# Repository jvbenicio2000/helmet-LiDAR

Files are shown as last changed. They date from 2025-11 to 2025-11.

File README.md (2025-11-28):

# Helmet-LiDAR

Capacete assistivo com sensor ultrassônico rotativo e feedback tátil vibratório para pessoas com deficiência visual.

## Descrição do Projeto

A ideia é fazer um capacete que consiga, através de um sensor ultrassônico que mede as distâncias e o uso de um motor de passo para movimentar este sensor 360°, acionar quatro motores que vibram e estão posicionados do lado direito, esquerdo, na frente e atrás de um usuário com deficiência visual, a fim de informá-lo se existem obstáculos na frente, atrás ou de qualquer um dos lados.

## Estrutura do Repositório

- **3D-Print:** Contém os arquivos de modelo 3D para a impressão das peças do capacete e suportes dos componentes.
- **Electronics:** Contém os esquemas elétricos, layout da placa de circuito impresso (PCI) e outras informações relacionadas à eletrônica do projeto.
- **Coding:** Contém o código-fonte para o microcontrolador (por exemplo, Arduino ou ESP32) que controla o sensor, os motores e a lógica do sistema.
- **Bill-of-Materials:** Contém a lista de todos os componentes eletrônicos e materiais necessários para a construção do projeto.

## Autores

- João Victor Benício
- Vinicius Macedo Escudeiro
- Bruno Xia
- Raul Perez Silva

### Instituição

Instituto Mauá de Tecnologia

## Matérias Relacionadas

- Instrumentação
- Microcontroladores

## Relatório do Projeto

Para uma documentação completa, incluindo a fundamentação teórica, detalhes de implementação, testes e resultados, consulte o relatório principal do projeto:

**[Relatório Final (PDF)](./relatorio_final.pdf)**

## Funcionalidade Adicional: Rastreamento GPS

Além do sistema de detecção de obstáculos, o projeto inclui uma funcionalidade secundária de **rastreamento por GPS**. Utilizando uma segunda Raspberry Pi Pico, o sistema lê as coordenadas de um módulo GPS NEO-6M e as transmite via Bluetooth para um dispositivo pareado, permitindo o monitoramento remoto da localização do usuário.

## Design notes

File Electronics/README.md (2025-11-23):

# Eletrônica

Esta pasta contém os arquivos relacionados ao hardware eletrônico do projeto, incluindo o esquema elétrico e, futuramente, o layout da Placa de Circuito Impresso (PCB).

## Esquema Elétrico (`schematic.jpeg`)

O arquivo `schematic.jpeg` apresenta o diagrama de conexões entre o microcontrolador Raspberry Pi Pico e os principais periféricos do sistema.

### Visão Geral dos Componentes

- **Microcontrolador (RP):** O cérebro do projeto é um Raspberry Pi Pico.
- **Driver do Motor de Passo (TMC2209):** Controla o `MOTOR DE PASSO` com alta precisão, responsável por girar o sensor ultrassônico.
- **Regulador de Tensão (VI):** Converte a `FONTE 9V` (conector J1) para uma tensão adequada para alimentar os componentes.
- **Conectores:**
  - `PH1` e `PH2`: Conexão para o sensor ultrassônico (Trigger e Echo).
  - `DIGITAIS PONTE H`: Conector de 8 pinos para os drivers L298N que acionam os motores de vibração.
  - `PWM'S`: Conector de 4 pinos para os sinais PWM que controlam a intensidade dos motores de vibração.
  - `J4`: Conector de 4 pinos, provavelmente para o módulo GPS ou outro periférico.

### Mapeamento de Pinos (Conforme o Esquema)

A tabela abaixo detalha as conexões entre o Raspberry Pi Pico e os demais componentes, conforme ilustrado no esquema elétrico.

| Pino (GPIO) do Pico | Componente Conectado | Função |
|---|---|---|
| GP0 - GP7 | Conector `DIGITAIS PONTE H` | Sinais de controle para os drivers L298N. |
| GP8 - GP11 | Conector `PWM'S` | Sinais PWM para os 4 motores de vibração. |
| GP12 | TMC2209 | Sinal de `STEP` para o motor de passo. |
| GP13 | TMC2209 | Sinal de `DIR` (Direção) para o motor de passo. |
| GP14 | Conector `PH1` | Sinal de `TRIGGER` para o sensor ultrassônico. |
| GP15 | Conector `PH2` | Sinal de `ECHO` do sensor ultrassônico. |
| GP21 | TMC2209 | Sinal de `EN` (Enable) para o driver do motor. |

**Observação Importante:** O mapeamento de pinos neste esquema elétrico **difere** do que está definido no arquivo `Coding/main.c`. Será necessário ajustar o código-fonte para refletir as conexões do hardware final ou vice-versa. O esquema representa a documentação de hardware mais recente.

## Projeto Proteus (`Proteus/`)

A subpasta `Proteus/` contém os arquivos de design do circuito e da PCB (Placa de Circuito Impresso) desenvolvidos no software Proteus.

- **`PCBProjeto.pdsprj`**: Este é o arquivo principal do projeto Proteus, que inclui tanto o diagrama esquemático quanto o layout da PCB.
- **`*.workspace`**: Arquivo de configuração do ambiente de trabalho (workspace) do Proteus, que salva as configurações da sua sessão de trabalho, como janelas abertas e zoom.

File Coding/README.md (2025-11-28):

# Código-Fonte

Esta pasta contém o código-fonte para o microcontrolador do projeto Helmet-LiDAR.

## `main.c`

- **Microcontrolador Alvo:** Raspberry Pi Pico
- **Linguagem:** C

### Descrição

Este é o programa principal que orquestra todo o funcionamento do capacete. A lógica implementada realiza as seguintes tarefas:

1.  **Controle do Motor de Passo:** Utiliza um driver TMC2209 para girar o motor de passo em um ciclo contínuo: 360° no sentido horário, seguido por 360° no sentido anti-horário.

2.  **Varredura do Ambiente:** Realiza 12 medições de distância com o sensor ultrassônico a cada volta completa (uma medição a cada 30°).

3.  **Leitura do Sensor Ultrassônico:** Envia um pulso de trigger e mede a duração do pulso de echo para calcular a distância de obstáculos em centímetros.

4.  **Controle dos Motores de Vibração:**
    - A intensidade da vibração é inversamente proporcional à distância medida (quanto mais perto o obstáculo, mais forte a vibração).
    - A direção do obstáculo, determinada pelo ângulo do motor de passo, define qual dos quatro motores de vibração será acionado:
        - **Motor A (Frente):** 0° a 90°
        - **Motor B (Direita):** 90° a 180°
        - **Motor C (Atrás):** 180° a 270°
        - **Motor D (Esquerda):** 270° a 360°
    - O controle da intensidade é feito via PWM (Pulse Width Modulation).

### Pinos Utilizados (Raspberry Pi Pico)

| Função | Pino (GPIO) |
|---|---|
| **Sensor Ultrassônico** | |
| TRIGGER | 2 |
| ECHO | 3 |
| **Motores de Vibração** | |
| Motor A (Frente) | 6 |
| Motor B (Direita) | 8 |
| Motor C (Atrás) | 10 |
| Motor D (Esquerda) | 12 |
| **Motor de Passo (TMC2209)** | |
| STEP | 13 |
| DIR | 21 |
| EN | 5 |

### Compilação

Para compilar este projeto, é necessário ter o ambiente de desenvolvimento para o Raspberry Pi Pico configurado. Siga o guia oficial "Getting started with Raspberry Pi Pico" para mais detalhes.

## `gps_bluetooth.py`

- **Microcontrolador Alvo:** Raspberry Pi Pico W
- **Linguagem:** MicroPython

### Descrição

Este script é responsável por uma funcionalidade secundária do projeto: **rastreamento por GPS e comunicação via Bluetooth**.

1.  **Leitura do GPS:** O código utiliza uma comunicação serial (UART) para ler os dados brutos (sentenças NMEA) de um módulo GPS NEO-6M.

2.  **Parsing de Dados:** Ele processa especificamente as sentenças `$GPRMC` ou `$GNRMC`, que contêm as informações essenciais de geolocalização (latitude e longitude).

3.  **Conversão de Coordenadas:** Converte o formato de coordenadas NMEA para o formato de graus decimais, que é mais comum e fácil de usar em mapas.

4.  **Transmissão Bluetooth:** As coordenadas de latitude e longitude formatadas são então enviadas via Bluetooth (usando um módulo HC-05) para um dispositivo pareado, como um smartphone. Isso permite o monitoramento remoto da localização do usuário.

### Pinos Utilizados (Raspberry Pi Pico)

| Função | Pino (GPIO) do Pico | Módulo |
|---|---|---|
| **GPS (UART 1)** | |
| TX | 4 | RX do NEO-6M |
| RX | 5 | TX do NEO-6M |
| **Bluetooth (UART 0)** | |
| TX | 0 | RX do HC-05 |
| RX | 1 | TX do HC-05 |

**Nota:** Este script opera de forma independente do `main.c` e requer uma segunda Raspberry Pi Pico, conforme especificado na lista de materiais.

## `gps_bluetooth.c` (Versão em C)

- **Microcontrolador Alvo:** Raspberry Pi Pico
- **Linguagem:** C (com Raspberry Pi Pico SDK)

### Descrição

Esta é a **versão em C** da funcionalidade de rastreamento GPS, convertida a partir do script MicroPython. As funcionalidades são idênticas:

1.  **Leitura do GPS:** Utiliza a UART1 para ler dados NMEA do módulo GPS NEO-6M.
2.  **Parsing de Dados:** Processa as sentenças `$GPRMC` ou `$GNRMC` para extrair status, latitude e longitude.
3.  **Conversão de Coordenadas:** Converte as coordenadas NMEA para o formato de graus decimais.
4.  **Transmissão Bluetooth:** Envia as coordenadas formatadas via UART0 para um módulo Bluetooth HC-05.

### Pinos Utilizados (Raspberry Pi Pico)

O mapeamento de pinos é o mesmo da versão em Python:

| Função | Pino (GPIO) do Pico | Módulo |
|---|---|---|
| **GPS (UART 1)** | |
| TX | 4 | RX do NEO-6M |
| RX | 5 | TX do NEO-6M |
| **Bluetooth (UART 0)** | |
| TX | 0 | RX do HC-05 |
| RX | 1 | TX do HC-05 |

### Compilação

Para compilar este código, é necessário ter o ambiente de desenvolvimento para o Raspberry Pi Pico SDK configurado. O código deve ser compilado junto com os arquivos de build do SDK (CMakeLists.txt, etc.).

## `main_enhanced.c` (Versão Aprimorada)

- **Microcontrolador Alvo:** Raspberry Pi Pico
- **Linguagem:** C

### Descrição

Esta é uma **versão aprimorada** do código `main.c`, com foco em melhorar a precisão e a estabilidade das medições do sensor ultrassônico.

### Melhorias Implementadas

1.  **Filtro de Média Móvel (`read_distance_filtered()`):**
    -   **Problema Resolvido:** Sensores ultrassônicos podem sofrer com leituras espúrias (picos de ruído) que geram dados incorretos e instáveis.
    -   **Solução:** Em vez de usar uma única leitura, esta função coleta **5 amostras** de distância em rápida sucessão.
    -   Ela então **descarta a menor e a maior** leitura (que são as mais prováveis de serem ruído) e calcula a **média das 3 leituras restantes**.
    -   **Resultado:** A distância retornada é muito mais estável e confiável, reduzindo falsos positivos e tornando a resposta do sistema de vibração mais consistente.

2.  **Código Mais Robusto:** A lógica de ordenação (bubble sort) garante que os valores mínimo e máximo sejam sempre descartados corretamente.

O restante da lógica (controle do motor de passo, PWM, etc.) permanece o mesmo, mas agora opera com dados de distância de maior qualidade.

## `gps_geofencing.py` (Versão Aprimorada com Geofencing)

- **Microcontrolador Alvo:** Raspberry Pi Pico W
- **Linguagem:** MicroPython

### Descrição

Esta é uma **versão avançada** do script de GPS, que adiciona a funcionalidade de **geofencing** (cercas virtuais) para reconhecer pontos de interesse pré-definidos.

### Melhorias e Funcionalidades

1.  **Filtro de Média Móvel (`get_filtered_position()`):**
    -   Assim como no `main_enhanced.c`, este código coleta múltiplas amostras de GPS para calcular uma posição média, resultando em uma localização muito mais estável e precisa.

2.  **Cálculo de Distância Haversine (`distance_m()`):**
    -   Implementa a fórmula de Haversine para calcular com precisão a distância em metros entre duas coordenadas geográficas, levando em conta a curvatura da Terra.

3.  **Geofencing com Waypoints (`check_location()`):**
    -   Você pode definir uma lista de **pontos de interesse** (waypoints) com nome, latitude, longitude e um raio em metros.
    -   O código verifica continuamente se a posição atual do usuário está dentro do raio de algum desses waypoints.

4.  **Notificações de Chegada (`main()`):**
    -   Quando o usuário entra na área de um waypoint, o sistema envia uma notificação via Bluetooth (ex: "Você chegou perto de: Casa").
    -   Ele evita notificações repetidas, enviando o aviso apenas uma vez ao entrar na área.

### Uso

-   **Personalize os Waypoints:** Edite a lista `WAYPOINTS` no código para adicionar os locais de interesse para o usuário.
-   **Ação Personalizada:** No laço principal, há um local marcado (`>>> AQUI você pode colocar a reação do sistema <<<`) onde você pode adicionar uma ação específica quando um waypoint é alcançado (ex: acender um LED, tocar um som, etc.).

## `CMakeLists.txt` (Arquivo de Build)

- **Ambiente:** Raspberry Pi Pico SDK (C/C++)

### Descrição

Este arquivo é um **script de build** para o sistema CMake, que automatiza o processo de compilação de todos os códigos-fonte em C (`.c`) do projeto para o Raspberry Pi Pico.

### Funcionalidades

1.  **Múltiplos Executáveis:** Ele está configurado para compilar **três executáveis independentes** a partir dos seus respectivos arquivos-fonte:
    -   `main` (a partir de `main.c`)
    -   `main_enhanced` (a partir de `main_enhanced.c`)
    -   `gps_bluetooth` (a partir de `gps_bluetooth.c`)

2.  **Gerenciamento de Bibliotecas:** Para cada executável, ele automaticamente vincula (linka) as bibliotecas necessárias do Pico SDK, como `pico_stdlib`, `hardware_pwm`, `hardware_uart`, etc.

3.  **Saída de Depuração:** Habilita a saída de `printf` via USB para todos os executáveis, facilitando a depuração.

4.  **Geração de Arquivos:** Automatiza a criação de todos os formatos de arquivo necessários para gravar no Pico, incluindo:
    -   `.uf2` (para arrastar e soltar na unidade do Pico)
    -   `.bin`
    -   `.hex`

### Como Usar

1.  **Configure o Ambiente:** Certifique-se de ter o [Raspberry Pi Pico SDK](https://github.com/raspberrypi/pico-sdk) e as ferramentas de compilação (CMake, GCC ARM) instalados.

2.  **Crie a Pasta de Build:** Dentro da pasta `Coding/`, crie uma subpasta chamada `build`:
    ```bash
    cd Coding
    mkdir build
    cd build
    ```

3.  **Execute o CMake e o Make:**
    ```bash
    cmake ..
    make
    ```

4.  **Grave no Pico:** Após a compilação, a pasta `build/` conterá os arquivos `.uf2` para cada um dos três executáveis. Basta arrastar o arquivo `.uf2` desejado para a unidade do Pico (que aparece ao conectar o Pico com o botão BOOTSEL pressionado).

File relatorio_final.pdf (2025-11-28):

## DISPOSITIVO VESTÍVEL DE AUXÍLIO À NAVEGAÇÃO PARA DEFICIENTES VISUAIS COM FEEDBACK TÁTIL, SENSORIAMENTO DE OBSTÁCULOS E RASTREAMENTO GPS

João Victor Benício ¹; Raul Perez ¹; Vinícius Escudeiro ¹; Bruno Xia ¹; Andressa Corrente Martins ²; Rodrigo França ²

¹ Aluno do Instituto Mauá de Tecnologia (IMT);

²Professor do Instituto Mauá de Tecnologia(IMT).

Resumo. Este relatório descreve o desenvolvimento de um dispositivo vestível projetado para auxiliar a navegação de deficientes visuais. O sistema integra uma cinta com feedback tátil, um protótipo de radar para detecção de obstáculos e um módulo GPS para rastreamento de localização. O projeto serve como uma investigação preliminar para um futuro Trabalho de Conclusão de Curso (TCC). O sistema é composto por dois circuitos independentes, garantindo a privacidade do usuário ao permitir a desativação do rastreamento por GPS. O primeiro circuito, baseado em um microcontrolador Raspberry Pi Pico W, gerencia um sensor de distância ultrassônico montado em um motor de passo para emular um radar, e aciona quatro motores vibratórios para fornecer feedback tátil direcional. O segundo circuito, também utilizando um Raspberry Pi Pico W, é dedicado ao módulo GPS e à comunicação Bluetooth com uma interface de monitoramento em um aplicativo móvel. O desenvolvimento abrangeu desde a concepção e teste de componentes até a montagem de um protótipo funcional e o desenvolvimento de uma placa de circuito impresso (PCB). Os resultados validam a viabilidade do conceito de feedback tátil para orientação espacial, ao mesmo tempo que expõem as limitações dos componentes de baixo custo, como o alcance do sensor ultrassônico e a precisão do motor de passo.

Introdução

O desenvolvimento de tecnologias assistivas tem como objetivo primordial a promoção da autonomia e da qualidade de vida para pessoas com deficiência. Para indivíduos com deficiência visual, a navegação em ambientes desconhecidos representa um desafio constante, muitas vezes dependendo de auxílios tradicionais como bengalas ou cães-guia. Com o avanço da microeletrônica e dos sistemas embarcados, surgem novas possibilidades para a criação de dispositivos mais sofisticados e eficazes.

Este projeto se insere nesse contexto como um estudo introdutório e exploratório para um futuro Trabalho de Conclusão de Curso (TCC), que ambiciona desenvolver um sistema completo para monitorar e instrumentar um jet-ski, permitindo que deficientes visuais possam pilotá-lo de forma segura através de auxílio tátil ou sonoro. O foco do presente trabalho é a concepção e validação de três subsistemas chave: uma interface de feedback tátil utilizando motores vibratórios, um protótipo de radar para detecção de obstáculos e um sistema de rastreamento de localização via GPS com interface móvel. A integração e o teste desses componentes visam avaliar a viabilidade da abordagem e identificar os desafios técnicos para o projeto final.

O objetivo geral deste trabalho é desenvolver e avaliar um protótipo de dispositivo vestível para auxílio à navegação de deficientes visuais, validando os conceitos de feedback tátil para orientação espacial, sensoriamento de obstáculos com um radar de baixo custo e monitoramento de localização por GPS. Os objetivos específicos incluem testar a interface com motores vibratórios, construindo uma cinta com quatro motores vibratórios e desenvolvendo um sistema que traduza a localização de obstáculos em feedback tátil, variando a intensidade da vibração de acordo com a proximidade. Além disso, busca-se desenvolver um protótipo de radar, montando e programando um sistema de varredura de ambiente utilizando um sensor de distância ultrassônico acoplado a um motor de passo, emulando o funcionamento de um radar para mapear obstáculos em 360°. Por fim, pretende-se analisar o módulo GPS e a comunicação Bluetooth, implementando um circuito independente com um módulo GPS para capturar coordenadas geográficas e transmiti-las via Bluetooth para um aplicativo móvel, compreendendo as dificuldades e limitações da tecnologia, especialmente em relação à privacidade e à estabilidade do sinal.

Material e Métodos

O projeto foi desenvolvido de forma incremental, em seis etapas principais. Na fase de idealização, definiu-se o escopo do projeto, os objetivos e a arquitetura geral do sistema, separando-o em dois subsistemas: radar com feedback tátil e GPS/comunicação. Em seguida, realizou-se a seleção e compra de componentes, escolhendo e adquirindo os dispositivos eletrônicos de acordo com critérios de funcionalidade, custo e disponibilidade.

Depois disso, foi feita a etapa de teste individual de componentes, na qual sensores, atuadores e microcontroladores foram avaliados separadamente para verificar o correto funcionamento e compreender o comportamento de cada um. Concluídos esses testes, passou-se à montagem em protoboard, integrando os componentes em um mesmo circuito, o que permitiu ajustar tanto o hardware quanto a lógica de programação de forma rápida e flexível.

Na sequência, ocorreu o desenvolvimento e a depuração do código. O firmware foi implementado em MicroPython e em linguagem C, conforme a necessidade de cada subsistema, com foco na interação entre sensores e atuadores e em requisitos de desempenho em tempo real. O código passou por ciclos sucessivos de teste e correção para melhorar a estabilidade e a resposta do sistema.

Por fim, foi projetado o esquemático do subsistema de radar, confeccionada a placa de circuito impresso (PCI) e soldados os componentes, resultando em uma montagem mais robusta e confiável em comparação à fase de prototipagem em protoboard.

Tabela 1 – Componentes utilizados no projeto

Componente | Quantidade Especificação | Função no Projeto
Microcontrolador | 2 | Raspberry Pi Pico W | Processamento central dos dois subsistemas
Sensor de Distância | 1 | HC-SR04 | Medição de distância para o radar
Motor de Passo | 1 | NEMA 17 (ou similar) | Rotação do sensor ultrassônico
Driver de Motor de Passo | 1 | TMC2209 | Controle preciso do motor de passo
Motores de Vibração | 4 | Com massa desbalanceada | Atuadores para feedback tátil
Driver Ponte H | 2 | L298N | Controle dos motores de vibração
Módulo GPS | 1 | Módulo GPS genérico | Aquisição de coordenadas geográficas
Módulo Bluetooth | 1 | Integrado ao Pico W | Comunicação com o aplicativo móvel
Placa de Circuito Impresso | 1 | Produzida pela Mauá | Integração dos componentes do subsistema de radar

Fonte de
Alimentação
- Baterias/Fonte
| | externa | Alimentação dos circuitos

Com o objetivo de garantir a privacidade do usuário, a arquitetura do sistema foi dividida em dois circuitos completamente independentes e sem comunicação de dados entre si. O primeiro subsistema é o núcleo da orientação espacial, controlado por um Raspberry Pi Pico W e composto por um radar sintético, uma lógica de atuação e o feedback tátil. O radar sintético consiste em um sensor ultrassônico HC-SR04 montado sobre um motor de passo que realiza uma varredura de 360°, parando em intervalos para que o sensor meça a distância até o obstáculo mais próximo em uma determinada direção. O sistema registra o número de passos do motor para derivar o ângulo de detecção. A lógica de atuação divide o espaço ao redor do usuário em quatro quadrantes (0-90°, 90-180°, 180-270°, 270-360°), e ao detectar um obstáculo, o sistema identifica em qual quadrante ele se encontra e aciona o motor de vibração correspondente. O feedback tátil é composto por quatro motores de vibração posicionados em uma cinta, correspondendo à frente (12h), lateral direita (3h), costas (6h) e lateral esquerda (9h). A intensidade da vibração de cada motor é inversamente proporcional à distância medida, fornecendo uma percepção intuitiva da proximidade do obstáculo.

O segundo subsistema opera de forma autônoma e é responsável pelo rastreamento de localização. Um segundo Raspberry Pi Pico W é conectado a um módulo GPS, lendo continuamente os dados de geolocalização (latitude, longitude, altitude, número de satélites). Os dados de GPS são transmitidos via Bluetooth para um smartphone, onde um aplicativo simples, desenvolvido na plataforma App Inventor, recebe e exibe os dados de localização, permitindo que um acompanhante possa monitorar a posição do usuário em tempo real.

Resultados e Discussão

O desenvolvimento do projeto permitiu alcançar resultados funcionais, validando a prova de conceito, mas também revelou desafios importantes. O sistema, especialmente durante a fase de testes em protoboard, operou conforme o esperado. O radar sintético foi capaz de realizar a varredura do ambiente, e o feedback tátil na cinta respondeu corretamente à detecção de obstáculos, com a intensidade da vibração variando de acordo com a distância. O subsistema de GPS também se mostrou funcional, capturando coordenadas e transmitindo-as com sucesso para o aplicativo de monitoramento, como demonstrado na Figura 1.

Figura 1 – Interface do aplicativo móvel exibindo dados de GPS em tempo real.

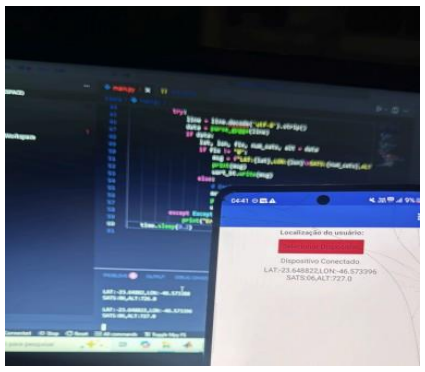
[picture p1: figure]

O desenvolvimento da placa de circuito impresso (Figura 2) para o subsistema de radar representou um avanço significativo em relação à montagem em protoboard, resultando em um protótipo mais estável e compacto. A PCB foi projetada utilizando software de design de circuitos e fabricada nas instalações do Instituto Mauá de Tecnologia. A soldagem dos componentes foi realizada manualmente, garantindo conexões confiáveis e reduzindo problemas de mau contato que eram frequentes na montagem em protoboard.

Figura 2 – Diagrama elétrico desenvolvida para o subsistema de radar.

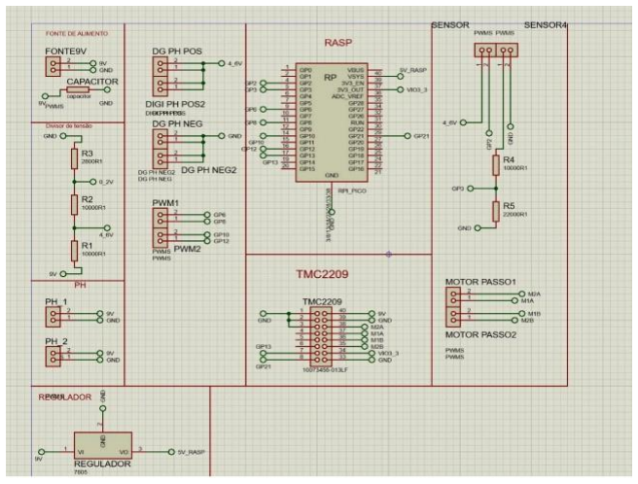
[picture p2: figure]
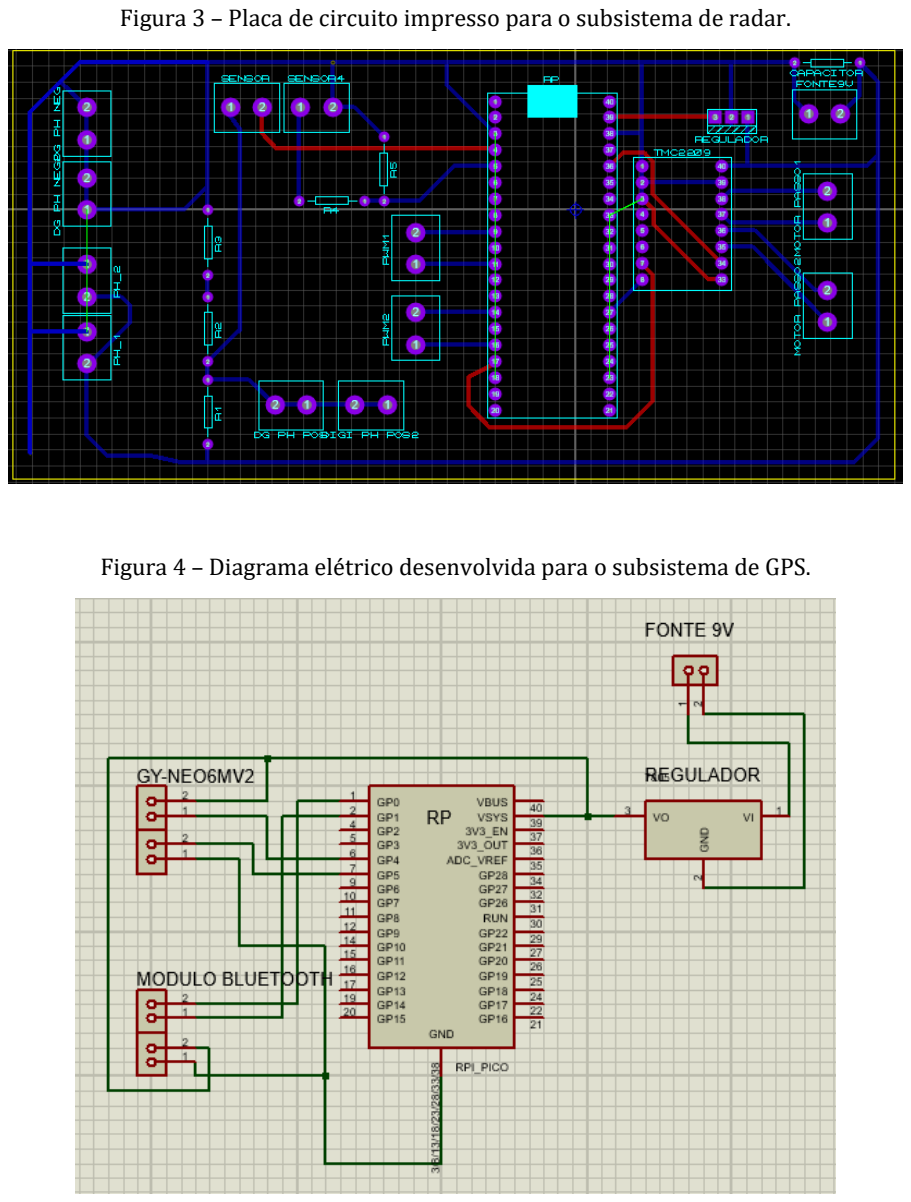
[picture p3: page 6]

Figura 3 – Placa de circuito impresso para o subsistema de radar.

Figura 4 – Diagrama elétrico desenvolvida para o subsistema de GPS.

Figura 5 – Placa de circuito impresso para o subsistema de GPS.

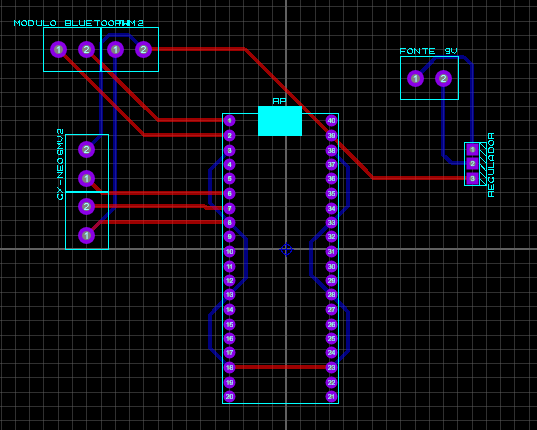
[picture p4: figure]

Rotinas de processamento de posição

O firmware de localização foi estruturado em um conjunto de rotinas responsáveis pelo tratamento das informações de GPS. Inicialmente, as sentenças NMEA recebidas do módulo são filtradas, sendo consideradas apenas aquelas do tipo RMC, por conterem latitude, longitude e o estado de validade da posição. Em seguida, as coordenadas no formato NMEA (ddmm.mmmm) são convertidas para graus decimais, o que facilita a aplicação de operações matemáticas e geodésicas.

Com o objetivo de reduzir o ruído inerente às medições de GPS, o sistema não utiliza uma leitura isolada. Em vez disso, são obtidas sucessivas posições válidas dentro de uma janela de tempo e, a partir delas, calcula-se a média das latitudes e das longitudes. Esse procedimento de filtragem por média aritmética resulta em uma posição geográfica mais estável e representativa do local real em que o dispositivo se encontra.

Uma vez determinada a posição filtrada, o firmware a compara com um conjunto de pontos de interesse pré-cadastrados (waypoints). Cada waypoint é definido por um nome, por uma coordenada em graus decimais e por um raio de detecção em metros. Para cada ponto cadastrado, é calculada a distância entre a posição atual e a posição de referência utilizando a fórmula de Haversine, que fornece uma boa aproximação da distância entre dois pontos na superfície terrestre. Quando a distância calculada é menor ou igual ao raio estabelecido para determinado waypoint, considera-se que o dispositivo se encontra dentro da área desse ponto, e o nome correspondente é retornado para uso nas demais partes do sistema.

Programa principal (função main)

A função main integra as rotinas descritas anteriormente e coordena o funcionamento contínuo do módulo de localização. Após a inicialização dos recursos necessários, o programa entra em um laço cíclico no qual, a cada iteração, solicita uma nova posição geográfica ao bloco de processamento. Caso não seja possível obter uma posição confiável naquele instante, o sistema apenas registra essa condição e informa a ausência de fix, sem alterar o estado dos demais subsistemas.

Quando uma posição válida é obtida, a função main utiliza o resultado filtrado de latitude e longitude para duas finalidades principais: (i) disponibilizar essas informações para fins de monitoramento e registro, e (ii) acionar a rotina de verificação de waypoints. Se essa verificação indicar que a posição atual se encontra dentro da área de algum ponto cadastrado, o programa identifica o nome do local correspondente e gera uma mensagem de chegada, que pode ser encaminhada a um dispositivo externo e/ou utilizada para disparar uma resposta física no protótipo, como a ativação de um indicador luminoso ou de outro atuador.

Dessa forma, o laço principal passa a funcionar como um monitor de localização em tempo real, responsável por transformar coordenadas brutas de GPS em eventos significativos para o projeto, tais como “entrada na área da loja” ou “aproximação de um ponto de interesse pré-definido”.

Desafios e dificuldades

Diversas dificuldades foram encontradas durante o desenvolvimento. O sensor ultrassônico HC-SR04, apesar de seu baixo custo, possui um alcance limitado e um cone de detecção relativamente amplo, o que pode levar a imprecisões. A velocidade de varredura é restrita pela necessidade de rotação do motor de passo e pelo tempo de resposta do sensor. Foi observado que, após uso contínuo, o motor de passo pode perder passos, resultando em um erro acumulado na determinação do ângulo e, consequentemente, na localização do feedback tátil. O módulo GPS apresentou dificuldade em obter sinal em ambientes fechados, uma limitação inerente à tecnologia. A comunicação via Bluetooth também se mostrou suscetível a interferências e perda de conexão com o aumento da distância entre o dispositivo e o smartphone. Problemas de mau contato nos conectores e fios foram uma fonte recorrente de falhas durante a fase de prototipagem. A integração do software com o hardware, especialmente a calibração da resposta do sensor de distância, exigiu depuração extensiva.

Conclusões

O projeto atingiu com sucesso seus objetivos principais, demonstrando a viabilidade de um sistema vestível com feedback tátil para auxílio à navegação. A prova de conceito validou que a utilização de motores vibratórios com intensidade variável é uma forma intuitiva e eficaz de comunicar informações espaciais sobre obstáculos ao usuário. As limitações encontradas, no entanto, são cruciais para a evolução do projeto. A montagem do radar sintético, embora funcional para validação, não se mostra robusta o suficiente para uma aplicação real devido às imprecisões do sensor ultrassônico e à perda de passos do motor. A resolução espacial do feedback, limitada a quatro quadrantes, também pode ser aprimorada para fornecer uma orientação mais precisa. Conclui-se que, embora a abordagem seja promissora, a transição para um produto final, como o sistema de auxílio para pilotagem de jet-ski, exigirá a substituição de componentes chave por soluções de nível comercial e maior robustez.

Com base nas conclusões deste trabalho, as seguintes melhorias são propostas para o desenvolvimento futuro do projeto, visando a aplicação no TCC. Primeiramente, propõe-se aumentar a resolução tátil, utilizando um número maior de motores vibratórios na cinta para fornecer uma indicação de direção mais granular e precisa. Em segundo lugar, sugere-se implementar feedback sonoro, adicionando um fone de ouvido ao sistema para fornecer informações complementares por áudio, como alertas de voz (“Obstáculo à direita”, “Velocidade: 10 km/h”), utilizando o conceito de áudio espacial para indicar a direção. Por fim, recomenda-se substituir o radar sintético, incorporando um módulo de radar comercial (tecnologia de micro-ondas ou LiDAR) para obter uma detecção de obstáculos mais rápida, precisa e com maior alcance, eliminando os problemas mecânicos do motor de passo.

Referências Bibliográficas

Bailey, D.D.; Ollis, D.F. (1986) Biochemical Engineering Fundamentals. 2ⁿᵈ edition. New York, McGraw-Hill.

Vela, F.J.; Gianotti, E.P.; Foresti, E.; Zaiat, M. (1999) Estimation of Substrate Effective Diffusivities in Anaerobic Bioparticles. Environmental Technology, 20, 1163-1170.

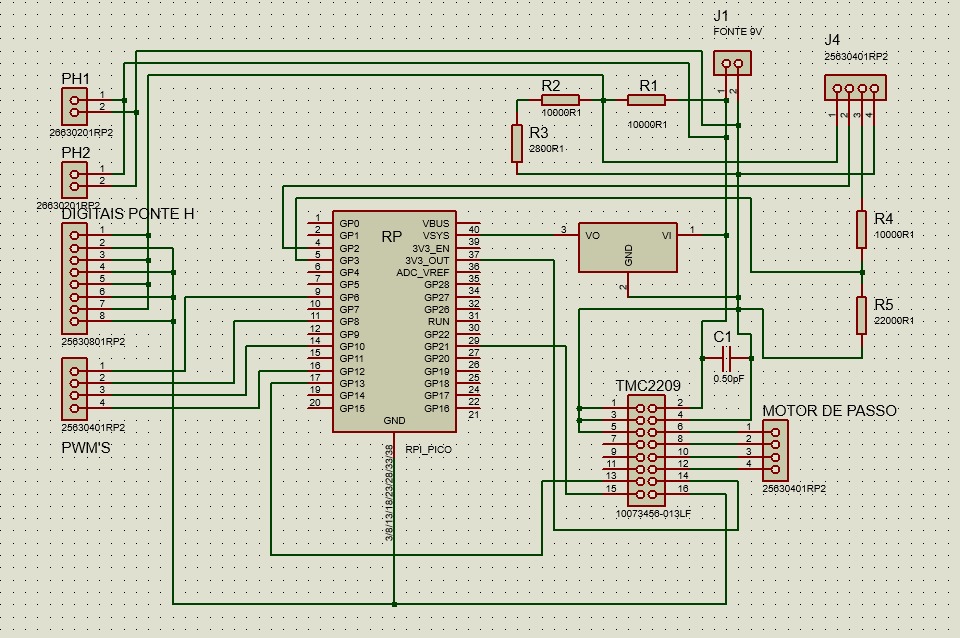
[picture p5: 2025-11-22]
Electronics/schematic.jpeg

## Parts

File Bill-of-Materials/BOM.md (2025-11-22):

# Lista de Materiais (Bill of Materials)

Esta é a lista de componentes e materiais necessários para a montagem completa do projeto Helmet-LiDAR.

| Categoria | Componente | Quantidade | Observações |
|---|---|---|---|
| **Microcontroladores** | Raspberry Pi Pico W | 2 | Um para o sistema principal e outro para funções auxiliares ou comunicação. |
| **Sensores** | Sensor Ultrassônico HC-SR04 | 1 | Para medição de distância. |
| | Módulo GPS NEO-6M | 1 | Para funcionalidades de geolocalização. |
| **Atuadores** | Motor de Passo NEMA 17 | 1 | Para a rotação do conjunto do sensor. |
| | Driver para Motor de Passo TMC2209 | 1 | Controla o motor de passo com precisão (microstepping). |
| | Motores de Vibração de Alta Intensidade | 4 | 12V, com massa desbalanceada para feedback tátil. |
| | Driver Ponte H L298N | 2 | Para controlar os quatro motores de vibração. |
| **Estrutura** | Capacete de Segurança | 1 | Base para a montagem de todos os componentes. |
| | Filamento para Impressão 3D (PLA/PETG) | - | Para imprimir todas as peças e suportes customizados. |
| **Eletrônica** | Placa de Circuito Impresso (PCB) | 1 | Para uma montagem final e robusta dos componentes eletrônicos. |
| | Fiação e Conectores Diversos | - | Para realizar todas as conexões elétricas. |
| **Alimentação** | Bateria / Fonte de Alimentação | 1 | Ex: Power Bank de alta capacidade ou conjunto de baterias Li-ion. |

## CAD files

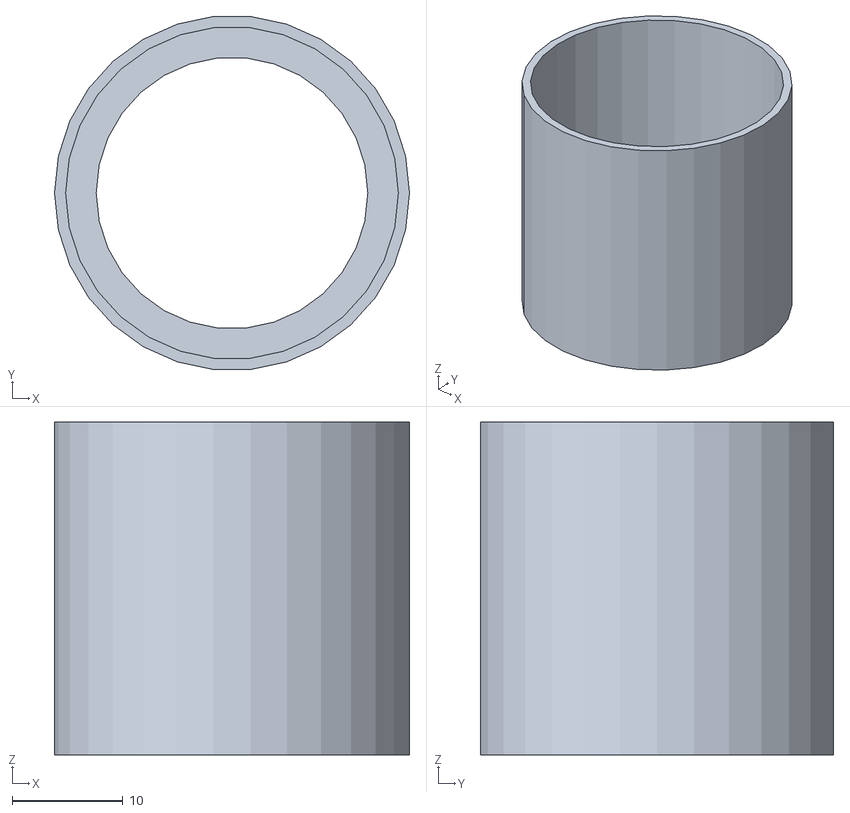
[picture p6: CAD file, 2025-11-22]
3D-Print/anel_peca_inferior.stl
32.0 x 31.8 x 30.0

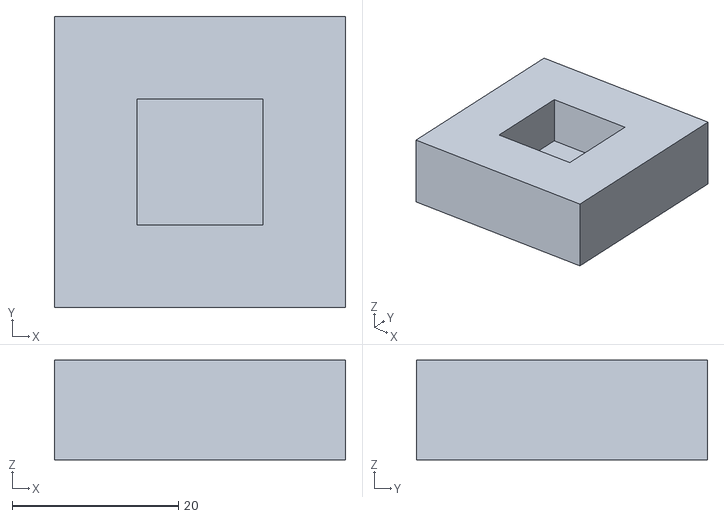
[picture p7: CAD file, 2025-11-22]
3D-Print/bloco_furo_centralizado.stl
35.0 x 35.0 x 12.0

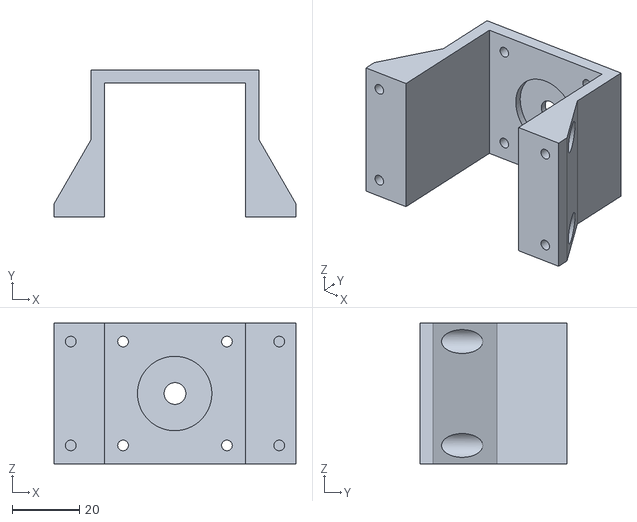
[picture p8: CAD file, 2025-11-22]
3D-Print/nema-17-mount-v1.stl
72.2 x 44.0 x 42.0

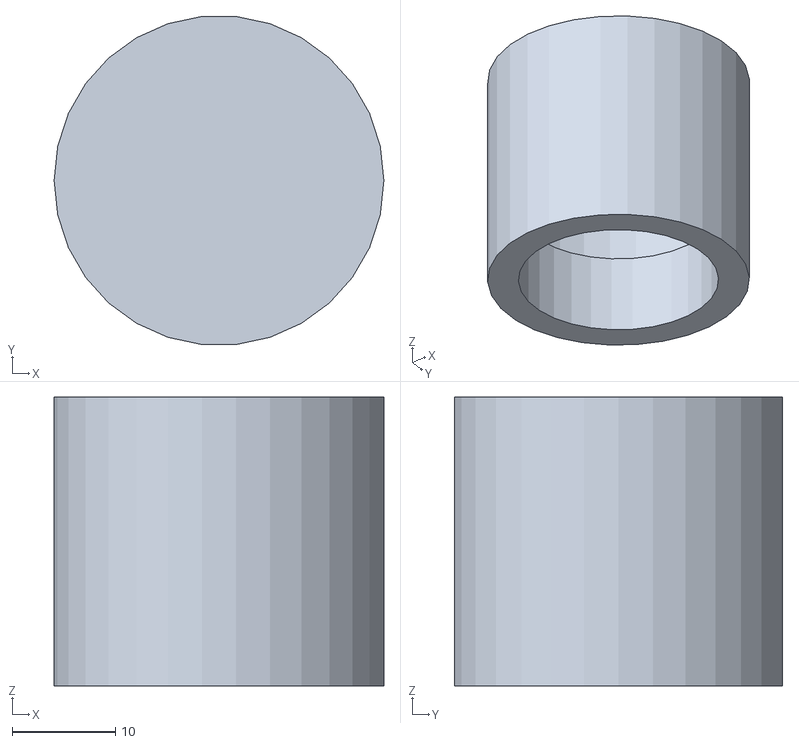
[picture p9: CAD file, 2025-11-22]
3D-Print/anel_complexo_v4.stl
32.0 x 31.8 x 28.0

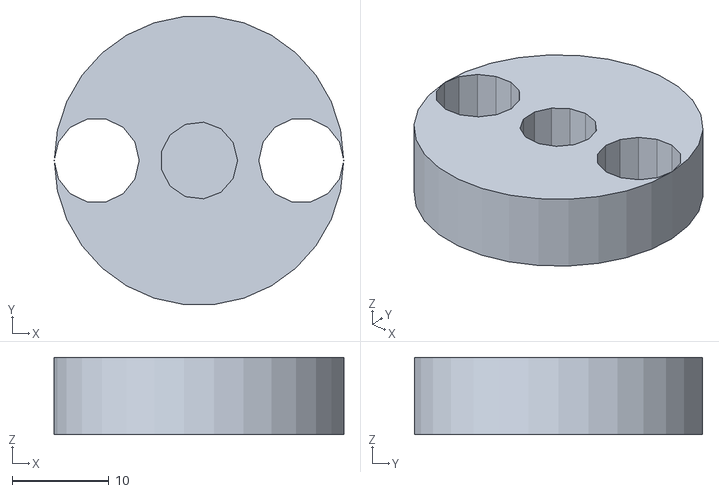
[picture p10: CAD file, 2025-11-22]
3D-Print/cilindro_furos_tangentes_v2.stl
30.0 x 29.8 x 8.00

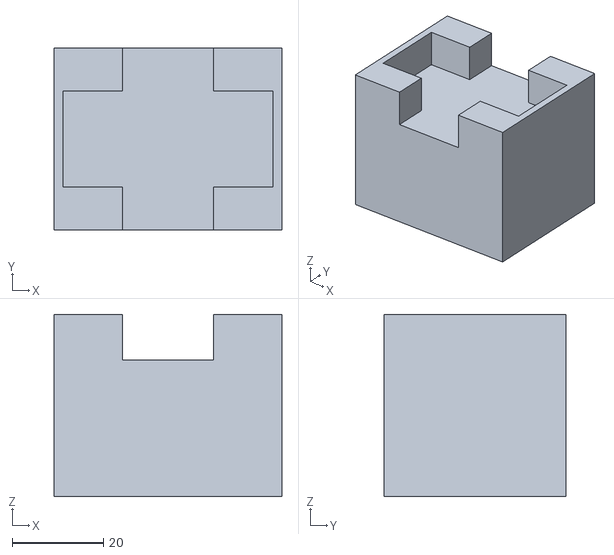
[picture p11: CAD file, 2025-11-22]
3D-Print/bloco_3_furos_v3.stl
50.0 x 40.0 x 40.0

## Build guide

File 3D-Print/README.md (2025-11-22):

# Modelos 3D

Esta pasta contém os arquivos de modelo 3D para a impressão das peças do projeto Helmet-LiDAR.

## Suporte do Sensor Ultrassônico

- **Arquivo:** `bloco_3_furos_v3.stl`
- **Descrição:** Este componente é o suporte projetado para acoplar o sensor ultrassônico (HC-SR04) ao motor de passo, permitindo a sua rotação para a varredura do ambiente.

## Outros Componentes

- **Arquivo:** `nema-17-mount-v1.stl`
- **Descrição:** Suporte para o motor de passo NEMA 17, responsável pela rotação do conjunto do sensor.

- **Arquivo:** `anel_complexo_v4.stl`
- **Descrição:** Anel superior do conjunto giratório, possivelmente para fixação de componentes.

- **Arquivo:** `cilindro_furos_tangentes_v2.stl`
- **Descrição:** Cilindro com furos tangenciais, provavelmente para passagem de fios ou como parte do acoplamento mecânico.

- **Arquivo:** `anel_peca_inferior.stl`
- **Descrição:** Anel inferior do conjunto giratório, complementando o `anel_complexo_v4.stl`.

- **Arquivo:** `bloco_furo_centralizado.stl`
- **Descrição:** Bloco com furo central, que pode ser usado como espaçador ou para acoplamento no eixo do motor.

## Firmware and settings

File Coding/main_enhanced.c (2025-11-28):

// main_enhanced.c
//
// Versão aprimorada do código principal com filtro de média móvel para o sensor ultrassônico.
//
// Varredura com motor de passo (TMC2209) + sensor ultrassônico,
// 4 motores vibratórios controlados por PWM.
// O motor gira 360° no sentido horário, depois 360° no sentido anti-horário,
// repetindo esse ciclo. São feitas 12 medições por volta (a cada 30°).
//
// Ajuste os parâmetros de microstepping conforme a configuração física do TMC2209.
//

#include <stdio.h>
#include "pico/stdlib.h"
#include "hardware/pwm.h"

// ------------------------
// Configurações gerais do motor de passo
// ------------------------

// Motor de 1,8° => 200 passos cheios por volta
#define FULL_STEPS_PER_REV        200

// Fator de microstep configurado no TMC2209 (ajuste conforme jumpers / UART)
// Exemplos típicos: 1, 2, 4, 8, 16...
#define MICROSTEPS                8

// Total de pulsos STEP necessários para 1 volta mecânica
#define STEPS_PER_REV   (FULL_STEPS_PER_REV * MICROSTEPS)

// Velocidade do motor de passo (ajuste para mais rápido ou mais devagar)
#define STEP_PULSE_US            50    // largura do pulso STEP em us
#define STEP_MIN_DELAY_US        100   // espera mínima entre passos em us

// ------------------------
// Configurações das medições
// ------------------------

// Número de medições desejadas por volta (pedido: 12 -> 360° / 12 = 30°)
#define MEASUREMENTS_PER_REV     12

// Separação angular entre medições (em graus)
#define ANGLE_BETWEEN_MEASUREMENTS  (360.0f / MEASUREMENTS_PER_REV)

// Distância máxima considerada (cm) para o mapeamento de intensidade
// Aqui começamos a "considerar obstáculo" a partir de 2,5 m.
#define MAX_DISTANCE_CM          250.0f

// Fator de suavização da intensidade (1 = sem suavização, >1 = suaviza mais)
#define SMOOTHING_FACTOR         10

// Habilitar prints de depuração (0 = desliga, 1 = liga)
#define DEBUG                    0

// ------------------------
// Definições p/ ultrassom
// ------------------------
#define TRIGGER_PIN 2
#define ECHO_PIN    3

// ------------------------
// Definições p/ motores de vibração (PWM)
// ------------------------
#define MOTOR_A_PIN 6
#define MOTOR_B_PIN 8
#define MOTOR_C_PIN 10
#define MOTOR_D_PIN 12

// ------------------------
// Definições p/ motor de passo + TMC2209
// ------------------------
#define STEP_PIN    13
#define DIR_PIN     21
#define EN_PIN      5

// ------------------------
// Variável global de ângulo (0..360)
// ------------------------
float angulo = 0.0f;

// ------------------------
// Funções auxiliares
// ------------------------

float read_distance_cm() {
    // Disparo do pulso no TRIGGER
    gpio_put(TRIGGER_PIN, true);
    sleep_us(10);
    gpio_put(TRIGGER_PIN, false);

    // Espera o início do ECHO (subida) com timeout
    uint32_t start_time = time_us_32();
    while (!gpio_get(ECHO_PIN) && (time_us_32() - start_time < 25000)) {
        // espera até ~25 ms para subida (equivalente a ~4 m)
    }

    // Se não subiu, retorna distância máxima (sem obstáculo próximo)
    if (!gpio_get(ECHO_PIN)) {
        return MAX_DISTANCE_CM;
    }

    uint32_t echo_start = time_us_32();

    // Espera o fim do ECHO (descida) com timeout
    while (gpio_get(ECHO_PIN) && (time_us_32() - echo_start < 25000)) {
        // espera até ~25 ms de pulso
    }

    uint32_t echo_end = time_us_32();

    // Cálculo da distância em cm (velocidade do som ~ 343 m/s)
    float distance = (echo_end > echo_start)
                     ? (echo_end - echo_start) / 2.0f / 29.1f
                     : MAX_DISTANCE_CM;

    if (distance > MAX_DISTANCE_CM) distance = MAX_DISTANCE_CM;
    if (distance < 0.0f)            distance = 0.0f;

    return distance;
}

// *** FUNÇÃO DE MELHORIA ***
// Lê 5 amostras, descarta a maior e a menor, e retorna a média das 3 restantes.
float read_distance_filtered(void) {
    const int N = 5;
    float vals[N];

    for (int i = 0; i < N; i++) {
        vals[i] = read_distance_cm();
        sleep_ms(2); // Pequena pausa entre leituras
    }

    // Ordena o array para facilitar a remoção do min/max
    for (int i = 0; i < N - 1; i++) {
        for (int j = i + 1; j < N; j++) {
            if (vals[j] < vals[i]) {
                float temp = vals[i];
                vals[i] = vals[j];
                vals[j] = temp;
            }
        }
    }

    // Calcula a média dos valores centrais (descarta o primeiro e o último)
    float sum = 0;
    for (int i = 1; i < N - 1; i++) {
        sum += vals[i];
    }
    float media = sum / (N - 2);

    return media;
}

void set_motor_pwm(uint gpio, uint16_t level) {
    uint slice   = pwm_gpio_to_slice_num(gpio);
    uint channel = pwm_gpio_to_channel(gpio);
    pwm_set_chan_level(slice, channel, level);
}

void init_motor_pwm(uint gpio) {
    gpio_set_function(gpio, GPIO_FUNC_PWM);
    uint slice = pwm_gpio_to_slice_num(gpio);
    pwm_set_wrap(slice, 1000);        // resolução do PWM (0..1000)
    pwm_set_enabled(slice, true);
}

// Dá 1 passo no motor de passo (1 micro-passo, conforme config do TMC2209)
void step_once(void) {
    gpio_put(STEP_PIN, 1);
    sleep_us(STEP_PULSE_US);
    gpio_put(STEP_PIN, 0);
    sleep_us(STEP_MIN_DELAY_US);
}

// Inicializa pinos do TMC2209 em modo STEP/DIR
void init_stepper_pins(void) {
    gpio_init(STEP_PIN);
    gpio_set_dir(STEP_PIN, GPIO_OUT);
    gpio_put(STEP_PIN, 0);

    gpio_init(DIR_PIN);
    gpio_set_dir(DIR_PIN, GPIO_OUT);
    // Vamos começar girando no sentido horário (valor lógico arbitrário)
    gpio_put(DIR_PIN, 1);

    gpio_init(EN_PIN);
    gpio_set_dir(EN_PIN, GPIO_OUT);
    // EN normalmente é ativo em nível baixo: 0 = habilita, 1 = desabilita
    gpio_put(EN_PIN, 0); // habilita o driver
}

int main() {
    stdio_init_all();

    // ------------------------
    // Inicializa ultrassom
    // ------------------------
    gpio_init(TRIGGER_PIN);
    gpio_set_dir(TRIGGER_PIN, GPIO_OUT);
    gpio_put(TRIGGER_PIN, false);

    gpio_init(ECHO_PIN);
    gpio_set_dir(ECHO_PIN, GPIO_IN);
    gpio_pull_down(ECHO_PIN);

    // ------------------------
    // Inicializa motores de vibração (PWM)
    // ------------------------
    init_motor_pwm(MOTOR_A_PIN);
    init_motor_pwm(MOTOR_B_PIN);
    init_motor_pwm(MOTOR_C_PIN);
    init_motor_pwm(MOTOR_D_PIN);

    // ------------------------
    // Inicializa motor de passo (TMC2209)
    // ------------------------
    init_stepper_pins();

    // Posição mecânica atual em passos (0..STEPS_PER_REV-1)
    int pos_step = 0;

    // Contador de passos dentro da volta atual
    int steps_in_rev = 0;

    // Direção atual: true = horário, false = anti-horário
    bool dir_cw = true;

    // Controle de medições por volta (baseado em passos)
    float steps_between_measures = (float)STEPS_PER_REV / (float)MEASUREMENTS_PER_REV;
    float next_measure_step = 0.0f;
    int measurements_this_rev = 0;

    // Intensidade suavizada
    uint16_t last_intensity = 0;

    // Distância atual (mantida entre medições para debug se quiser)
    float distancia = MAX_DISTANCE_CM;

    while (true) {
        // ------------------------
        // Salva ângulo anterior
        // ------------------------
        float angulo_anterior = angulo;

        // ------------------------
        // Dá 1 micro-passo no motor de passo
        // ------------------------
        step_once();

        // Atualiza posição mecânica em função da direção
        if (dir_cw) {
            pos_step++;
            if (pos_step >= STEPS_PER_REV) {
                pos_step = 0;
            }
        } else {
            if (pos_step == 0) {
                pos_step = STEPS_PER_REV - 1;
            } else {
                pos_step--;
            }
        }

        // Atualiza contagem de passos na volta atual
        steps_in_rev++;

        // Converte posição em ângulo (0..360)
        angulo = (pos_step * 360.0f) / (float)STEPS_PER_REV;
        if (angulo >= 360.0f) {
            angulo -= 360.0f;
        }

        // ------------------------
        // Verifica se é hora de medir (12 vezes por volta)
        // ------------------------
        bool do_measure = false;
        if ((float)steps_in_rev >= next_measure_step &&
            measurements_this_rev < MEASUREMENTS_PER_REV) {

            do_measure = true;
            measurements_this_rev++;
            next_measure_step += steps_between_measures;
        }

        if (do_measure) {
            // ------------------------
            // Mede distância (usando a função com filtro)
            // ------------------------
            distancia = read_distance_filtered();

            // Calcula intensidade de vibração (0..1000)
            float raw_intensity =
                1000.0f * (MAX_DISTANCE_CM - distancia) / MAX_DISTANCE_CM;

            if (raw_intensity < 0.0f)   raw_intensity = 0.0f;
            if (raw_intensity > 1000.0f) raw_intensity = 1000.0f;

            uint16_t intensidade = (uint16_t)raw_intensity;

            // Suaviza a intensidade
            intensidade = (uint16_t)(
                (last_intensity * (SMOOTHING_FACTOR - 1) + intensidade)
                / SMOOTHING_FACTOR
            );
            last_intensity = intensidade;

            // ------------------------
            // Lógica de ângulo -> motor A/B/C/D
            // ------------------------
            uint16_t A = 0, B = 0, C = 0, D = 0;

            if (angulo >= 0.0f && angulo < 90.0f) {
                A = intensidade;
            } else if (angulo >= 90.0f && angulo < 180.0f) {
                B = intensidade;
            } else if (angulo >= 180.0f && angulo < 270.0f) {
                C = intensidade;
            } else if (angulo >= 270.0f && angulo < 360.0f) {
                D = intensidade;
            }

            // Aplica PWM nos motores de vibração
            set_motor_pwm(MOTOR_A_PIN, A);
            set_motor_pwm(MOTOR_B_PIN, B);
            set_motor_pwm(MOTOR_C_PIN, C);
            set_motor_pwm(MOTOR_D_PIN, D);

            // Depuração opcional
        #if DEBUG
            printf("Dir: %s, passo=%d/%d, ang=%.2f, dist=%.2f cm, int=%u\n",
                   dir_cw ? "CW" : "CCW",
                   steps_in_rev, STEPS_PER_REV,
                   angulo, distancia, intensidade);
        #endif

            // Pequena pausa opcional após medição (se o sensor precisar)
            sleep_ms(2);
        }

        // ------------------------
        // Verifica fim da volta
        // ------------------------
        if (steps_in_rev >= STEPS_PER_REV) {
            // Reseta contadores da volta
            steps_in_rev = 0;
            measurements_this_rev = 0;
            next_measure_step = 0.0f;

            // Inverte a direção:
            // se estava horário (CW), passa para anti-horário (CCW) e vice-versa
            dir_cw = !dir_cw;
            gpio_put(DIR_PIN, dir_cw ? 1 : 0);

        #if DEBUG
            printf("Mudando direção para: %s\n", dir_cw ? "CW" : "CCW");
        #endif
        }
    }

    return 0;
}

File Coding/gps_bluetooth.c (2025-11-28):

// gps_bluetooth.c
//
// Sistema de rastreamento GPS com transmissão Bluetooth
// Lê coordenadas do módulo GPS NEO-6M e transmite via Bluetooth HC-05
// Raspberry Pi Pico SDK
//

#include <stdio.h>
#include <string.h>
#include <stdlib.h>
#include "pico/stdlib.h"
#include "hardware/uart.h"

// Configuração das UARTs
#define UART_GPS_ID uart1
#define UART_GPS_TX_PIN 4
#define UART_GPS_RX_PIN 5
#define UART_GPS_BAUD 9600

#define UART_BT_ID uart0
#define UART_BT_TX_PIN 0
#define UART_BT_RX_PIN 1
#define UART_BT_BAUD 9600

// Buffer para leitura de sentenças NMEA
#define NMEA_BUFFER_SIZE 256

// Estrutura para armazenar coordenadas GPS
typedef struct {
    double latitude;
    double longitude;
    bool valid;
} GPSCoordinates;

// Função para converter coordenadas NMEA para decimal
double nmea_to_decimal(const char* coord_str, char direction) {
    if (!coord_str || strlen(coord_str) == 0) {
        return 0.0;
    }

    double coord = atof(coord_str);
    
    // Extrai graus e minutos
    int degrees = (int)(coord / 100);
    double minutes = coord - (degrees * 100);
    
    // Converte para decimal
    double decimal = degrees + (minutes / 60.0);
    
    // Aplica sinal baseado na direção
    if (direction == 'S' || direction == 'W') {
        decimal = -decimal;
    }
    
    return decimal;
}

// Função para fazer parsing da sentença GPRMC/GNRMC
GPSCoordinates parse_gprmc(const char* sentence) {
    GPSCoordinates coords = {0.0, 0.0, false};
    
    // Cria uma cópia da sentença para tokenização
    char buffer[NMEA_BUFFER_SIZE];
    strncpy(buffer, sentence, NMEA_BUFFER_SIZE - 1);
    buffer[NMEA_BUFFER_SIZE - 1] = '\0';
    
    // Tokeniza a sentença usando vírgula como delimitador
    char* token = strtok(buffer, ",");
    int field_count = 0;
    
    char lat_str[16] = {0};
    char lat_dir = 0;
    char lon_str[16] = {0};
    char lon_dir = 0;
    char status = 0;
    
    while (token != NULL && field_count < 10) {
        switch (field_count) {
            case 2: // Status (A = válido, V = inválido)
                status = token[0];
                break;
            case 3: // Latitude
                strncpy(lat_str, token, sizeof(lat_str) - 1);
                break;
            case 4: // Direção da latitude (N/S)
                lat_dir = token[0];
                break;
            case 5: // Longitude
                strncpy(lon_str, token, sizeof(lon_str) - 1);
                break;
            case 6: // Direção da longitude (E/W)
                lon_dir = token[0];
                break;
        }
        
        token = strtok(NULL, ",");
        field_count++;
    }
    
    // Verifica se o status é válido
    if (status == 'A' && strlen(lat_str) > 0 && strlen(lon_str) > 0) {
        coords.latitude = nmea_to_decimal(lat_str, lat_dir);
        coords.longitude = nmea_to_decimal(lon_str, lon_dir);
        coords.valid = true;
    }
    
    return coords;
}

// Função para enviar dados via Bluetooth
void bt_send(const char* text) {
    if (text) {
        uart_puts(UART_BT_ID, text);
    }
}

// Inicializa as UARTs
void init_uarts(void) {
    // Inicializa UART do GPS
    uart_init(UART_GPS_ID, UART_GPS_BAUD);
    gpio_set_function(UART_GPS_TX_PIN, GPIO_FUNC_UART);
    gpio_set_function(UART_GPS_RX_PIN, GPIO_FUNC_UART);
    
    // Inicializa UART do Bluetooth
    uart_init(UART_BT_ID, UART_BT_BAUD);
    gpio_set_function(UART_BT_TX_PIN, GPIO_FUNC_UART);
    gpio_set_function(UART_BT_RX_PIN, GPIO_FUNC_UART);
}

int main() {
    // Inicializa stdio
    stdio_init_all();
    
    // Inicializa as UARTs
    init_uarts();
    
    printf("Iniciando GPS... Vá para perto de uma janela.\n");
    bt_send("Sistema GPS iniciado\n");
    
    char nmea_buffer[NMEA_BUFFER_SIZE];
    int buffer_index = 0;
    
    while (true) {
        // Verifica se há dados disponíveis na UART do GPS
        if (uart_is_readable(UART_GPS_ID)) {
            char ch = uart_getc(UART_GPS_ID);
            
            // Verifica fim de linha
            if (ch == '\n' || ch == '\r') {
                if (buffer_index > 0) {
                    // Termina a string
                    nmea_buffer[buffer_index] = '\0';
                    
                    // Verifica se é uma sentença GPRMC ou GNRMC
                    if (strncmp(nmea_buffer, "$GPRMC", 6) == 0 || 
                        strncmp(nmea_buffer, "$GNRMC", 6) == 0) {
                        
                        GPSCoordinates coords = parse_gprmc(nmea_buffer);
                        
                        if (coords.valid) {
                            // Formata e envia as coordenadas
                            char output[128];
                            snprintf(output, sizeof(output), 
                                    "Lat: %.6f, Lon: %.6f\n", 
                                    coords.latitude, coords.longitude);
                            
                            printf("GPS: %s", output);
                            bt_send(output);
                        } else {
                            printf("Sem fix GPS\n");
                            bt_send("Sem sinal GPS\n");
                        }
                    }
                    
                    // Reseta o buffer
                    buffer_index = 0;
                }
            } else {
                // Adiciona caractere ao buffer
                if (buffer_index < NMEA_BUFFER_SIZE - 1) {
                    nmea_buffer[buffer_index++] = ch;
                } else {
                    // Buffer cheio, reseta
                    buffer_index = 0;
                }
            }
        }
        
        // Pequeno delay para não sobrecarregar a CPU
        sleep_ms(5);
    }
    
    return 0;
}

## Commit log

2025-11-22 Initial commit: Estrutura do projeto Helmet-LiDAR com pastas 3D-Print, Electronics, Coding e Bill-of-Materials
2025-11-22 Adiciona modelo 3D do suporte do sensor ultrassônico
    [bloco_3_furos_v3.stl]
2025-11-22 Adiciona modelos 3D adicionais: suporte NEMA 17, anéis e componentes do conjunto giratório
    [anel_complexo_v4.stl, anel_peca_inferior.stl, bloco_furo_centralizado.stl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]
2025-11-22 Adiciona código-fonte principal (main.c) para Raspberry Pi Pico
2025-11-22 Atualiza BOM com lista completa de componentes, incluindo GPS, bateria e fiação
2025-11-22 Adiciona esquema elétrico e documentação de hardware
2025-11-23 Adiciona arquivos do projeto Proteus (esquemático e layout de PCB)
2025-11-28 Adiciona versão em C do código GPS/Bluetooth (convertido de Python)
2025-11-28 Adiciona versão aprimorada do código principal com filtro de média móvel
2025-11-28 Adiciona versão aprimorada do GPS com geofencing e filtro de média móvel
2025-11-28 Adiciona CMakeLists.txt para facilitar compilação dos códigos C
2025-11-28 Remove relatório PDF antigo para adicionar nova versão
